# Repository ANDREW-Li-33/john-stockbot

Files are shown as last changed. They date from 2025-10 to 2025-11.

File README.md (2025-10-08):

# John Stockbot
*A Mobile Autonomous Basketball Rebounding & Training Machine*

## About

John Stockbot is an autonomous robot designed to catch basketballs before they hit the ground and pass them back to players during practice sessions. Named after NBA legend John Stockton (the all-time assists leader), this robot aims to be the ultimate robotic training partner for basketball players.

The robot uses computer vision to track basketball trajectories in real-time, positions itself to intercept shots, and uses a dual-flywheel system to return passes to anywhere on the court. The system is built on a distributed architecture with a Jetson Orin Nano handling high-level intelligence and a Teensy 4.1 managing motor control.

## Design Documents

| Document | Description | Link |
|---|---|---|
| **Primary Objectives** | Project goals, success metrics, and development principles | [Google Doc](https://docs.google.com/document/d/1Vo0fm0xn1nyjWS2_vyuDy4Y2yRpmGPdnU__JquevN0A/edit?tab=t.0) |
| **System Architecture** | Technical design, ROS2 nodes, and communication protocols | [Google Doc](https://docs.google.com/document/d/1LGaEFNWjZb3376pkYbGlLpHBF5ra2i3nYetyKKqaXto/edit?usp=sharing) |
| **Development Timeline** | 8-week development roadmap and phases | [Google Doc](https://docs.google.com/document/d/1ajr8lFJE9e5p4RsDfiWhvAvUYR6jIlyunh-4V3jgzBY/edit?usp=sharing) |
| **Parts List** | Complete bill of materials with costs and vendors | [Google Doc](https://docs.google.com/document/d/1YOarMHOIX9Ntcbo915CyfLngcIprZ0BvidMgzt3DbME/edit?usp=sharing) |
| **Progress Log** | A log documenting progress and steps taken each day | [Google Doc](https://docs.google.com/document/d/12o3Nwnd-CbdC7QZ4ZfDTg3oS7z87Sn4MFR_PtwYzXlk/edit?tab=t.0) |

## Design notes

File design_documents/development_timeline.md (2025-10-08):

## Project Duration: 9 Weeks

### Phase 1: Foundation (Weeks 1-3)

**Goal**: Establish core infrastructure and validate critical subsystems

* Model and design staging mechanism, feeding mechanism, and mobile base
* Finalize complete parts list and order remaining components:
    * Battery system
    * Staging mechanism parts
    * Feeding mechanism parts
    * Drivetrain components (motors, controllers, wheel mounts)
* Complete mechanical assembly of static platform
* Set up development environment (ROS2, CUDA, simulation)
* Validate sensor pipeline (ZED Mini → Jetson)
* Initial motor control testing (Teensy → motors)

**Key Milestone**: Subsystems fully assembled

### Phase 2: Core Functionality (Weeks 4-5)

**Goal**: Achieve basic catch and return capability

* Implement trajectory prediction algorithms
* Develop staging mechanism control software
* Tune flywheel launching
* Program ball capture/containment system
* Design ROS2 nodes for mobility (architecture preparation)
* Start basic drivetrain firmware development on Teensy
* Integration of vision → control pipeline

**Key Milestone**: First successful catch and return of stationary-launched ball

### Phase 3: Mobility Integration (Weeks 6-7)

**Goal**: Add mobile platform capabilities

* Week 6 - Physical Assembly:
    * Mount omni wheels to base
    * Install drivetrain motors and controllers
    * Connect motor controllers to Teensy
    * Attach static platform to mobile base
* Week 7 - Software Implementation:
    * Implement X-drive kinematics
    * Test basic movement commands
    * Develop path planning to intercept points
    * Create court awareness and boundary detection
    * Test mobile interception strategies

**Key Milestone**: First successful mobile intercept

### Phase 4: System Refinement (Weeks 8-9)

**Goal**: Polish, optimize performance, and prepare for extended use

* Full system integration testing
* Performance optimization to reach target metrics
* Implement adaptive trajectory prediction
* Add player detection and tracking
* Refine launch accuracy and power control
* Safety validation and failure mode testing
* Documentation and code cleanup
* Demo video preparation

**Key Milestone**: 90% catch rate achieved, 1-hour autonomous operation demo

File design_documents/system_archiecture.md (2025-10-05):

# John Stockbot - System Architecture

## Rationale

The system employs a** **hierarchical, distributed architecture combining high-level intelligence on the Jetson Orin Nano with real-time control on the Teensy 4.1. This separation removes computationally intensive vision processing from the Teensy’s precise but computationally constrained motor control capabilities, ensuring deterministic response times for safety-critical operations. The ROS2 framework provides standardized interfaces and tools for debugging, while the distributed nature ensures that a failure in one subsystem doesn't flow to others, improving overall system reliability.

## System Overview

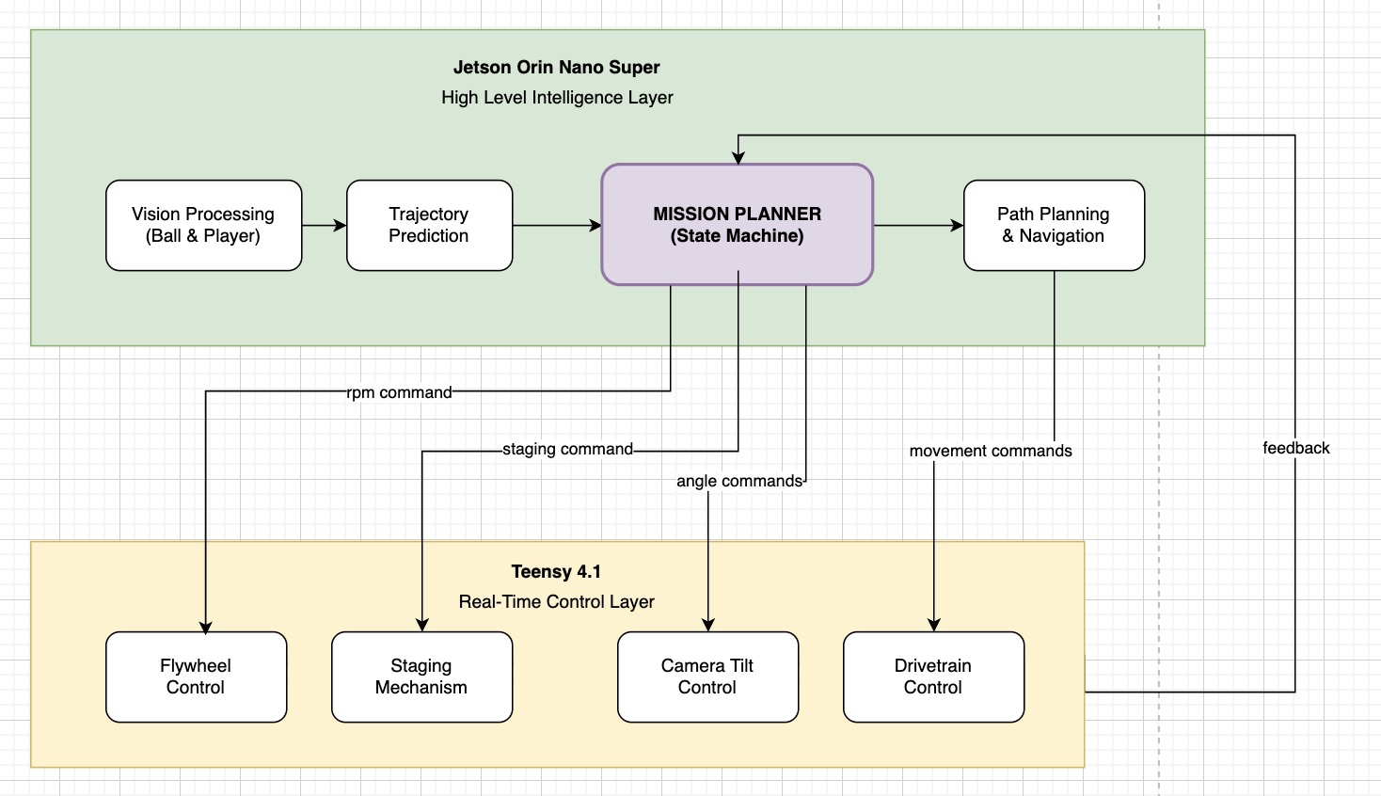
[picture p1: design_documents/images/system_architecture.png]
system_architecture image_tooltip


## Layer 1: Perception & Intelligence (Jetson Orin Nano)

### Vision Processing Node

**Responsibility**: Process ZED Mini camera data for object detection and tracking

* **Input**: RGB-D and depth stream
* **Processing**:
    * Ball detection using color segmentation + Hough circles
    * Player detection using pose estimation (OpenPose or MediaPipe)
    * Court boundary detection via line detection
* **Output**: Object positions in 3D world coordinates
* **Update Rate**: 30 Hz minimum

### Trajectory Prediction Node

**Responsibility**: Calculate ball flight path and intercept point

* **Input**: Ball position history (last 5-10 frames)
* **Processing**:
    * Kalman filter for state estimation
    * Physics model with drag coefficient
    * Confidence scoring for predictions
* **Output**: Predicted intercept point and time
* **Update Rate**: 30 Hz

### Mission Planning Node

**Responsibility**: High-level decision making and state management

* **States**:
    1. IDLE - Waiting for ball detection
    2. TRACKING - Following ball trajectory
    3. INTERCEPTING - Moving to catch position
    4. CATCHING - Executing catch sequence
    5. STAGING - Preparing ball for launch
    6. AIMING - Calculating launch parameters
    7. LAUNCHING - Executing pass
* **Output**: State commands and target positions
* **Update Rate**: 10 Hz

### Path Planning Node (Mobile Configuration)

**Responsibility**: Calculate optimal paths for interception

* **Input**: Current position, target intercept point, obstacles
* **Algorithm**: A* or RRT* for real-time planning
* **Output**: Waypoint sequence for drivetrain
* **Update Rate**: 10 Hz

## Layer 2: Real-Time Control (Teensy 4.1)

### Communication Interface

* **Protocol**: Custom binary protocol over Serial
* **Message Types**:
    * Motor commands (position, velocity, acceleration)
    * Sensor requests (encoder, IMU, limit switches)
    * Status updates (faults, temperatures, battery)
* **Bandwidth**: ~10 KB/s at 100 Hz update rate

### Flywheel Controller

**Responsibility**: Manage dual-motor flywheel system

* **Control Mode**: Closed-loop RPM control via ESCs
* **Sensors**: Hall effect for RPM feedback
* **Safety**: Soft-start, over-current protection
* **Performance**: 0-6000 RPM in &lt;2 seconds

### Staging Mechanism Controller

**Responsibility**: Control ball feeding into flywheel

* **Actuator**: NEMA 17 stepper with TMC2209 driver
* **Control**: Position control with AccelStepper library
* **Feedback**: Limit switches for home/end positions
* **Sequence**: Home → Load → Stage → Push → Retract

### Drivetrain Controller (Mobile Configuration)

**Responsibility**: Execute omnidirectional movement

* **Configuration**: 4-wheel X-drive with omni wheels
* **Control**: Inverse kinematics for wheel speeds
* **Feedback**: Encoder-based odometry
* **Performance**: 2 m/s max speed, 1 m/s² acceleration

### Camera Tilt Controller

**Responsibility**: Tilt camera for optimal tracking

* **Actuator**: NEMA 17 stepper motor
* **Control**: Position tracking of ball trajectory
* **Update Rate**: 50 Hz

## Scalability & Future Enhancements

### Modular Expansions

* LIDAR obstacle detection for navigation
* Speaker and microphone for user interaction

### Software Enhancements

* Shot prediction from player pose
* Handle and stage multiple balls simultaneously

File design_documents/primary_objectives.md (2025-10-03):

# John Stockbot - Primary Objectives
*Autonomous Basketball Rebounding & Training Assistant*

## Mission Statement
Develop an autonomous robot capable of intercepting basketballs in flight and returning them to players, initially as a static platform with future mobility capabilities.

## Core Objectives

### 1. Ball Detection & Tracking (Priority: Critical)
- **Objective**: Achieve robust real-time basketball detection and trajectory prediction
- **Success Metrics**:
  - Detection rate: >95% of shots from NBA 3-point line
  - Tracking latency: <50ms from detection to trajectory calculation
  - Trajectory prediction accuracy: ±20cm at intercept point
- **Key Requirements**:
  - Process ZED Mini depth + RGB data at minimum 30 FPS
  - Handle varying lighting conditions on indoor court
  - Track ball spin and account for Magnus effect in trajectory

### 2. Ball Interception (Priority: Critical)
- **Objective**: Successfully catch basketballs before ground contact
- **Success Metrics**:
  - Catching success rate: >90% for predicted intercepts within range
  - No damage to ball or safety hazards
  - Reliable ball containment post-catch
- **Key Requirements**:
  - Position accuracy: ±15cm at intercept point
  - Timing precision: ±100ms for intercept
  - Safe deceleration of ball momentum

### 3. Ball Return System (Priority: High)
- **Objective**: Return caught balls to player efficiently
- **Success Metrics**:
  - Launch consistency: ±1m accuracy at 10m distance
  - Return time: <3 seconds from catch to launch
  - Adjustable pass strength for various distances
- **Key Requirements**:
  - Flywheel speed control for variable pass distance (3-15m)
  - Reliable ball staging and feeding mechanism
  - Safety shutoff if player is too close

### 4. Platform Mobility (Priority: Medium - Phase 2)
- **Objective**: Enable autonomous navigation to optimal intercept positions
- **Success Metrics**:
  - Movement speed: >2 m/s
  - Positioning accuracy: ±10cm
  - Zero-turn capability for quick orientation changes
- **Key Requirements**:
  - Smooth omnidirectional movement via X-drive
  - Dynamic path planning to intercept point
  - Collision avoidance with court boundaries/obstacles

### 5. System Integration (Priority: High)
- **Objective**: Seamless coordination between all subsystems
- **Success Metrics**:
  - End-to-end latency: <200ms from detection to motion command
  - System reliability: >95% uptime during operation
  - Graceful failure handling
- **Key Requirements**:
  - Real-time communication between Jetson and Teensy
  - Synchronized control loops at 100Hz minimum
  - Robust error recovery mechanisms

## Development Principles

### Safety First
- Emergency stop capability at all times
- Soft-start for all motors
- Protected pinch points and moving parts
- Clear operational boundaries

### Iterative Development
- Start with static operation, validate core functionality
- Add mobility only after catching/passing proven
- Continuous testing on real court with real shots

### Modular Architecture
- Independent testing of each subsystem
- Clear interfaces between modules
- Version control for both hardware and software iterations

## Success Criteria for MVP (Month 1)
1. ✓ Detect and track basketball from 3-point line
2. ✓ Predict trajectory with <30cm error
3. ✓ Successfully catch 75% of straight shots
4. ✓ Return ball to fixed position via flywheel
5. ✓ Operate safely for 30-minute sessions

## Success Criteria for Version 1.0 (Month 2)
1. ✓ All MVP criteria at improved metrics
2. ✓ Mobile platform operational
3. ✓ Dynamic positioning for intercepts
4. ✓ Catch rate >90% within operational envelope
5. ✓ Variable distance passing with player tracking
6. ✓ 1-hour continuous operation capability

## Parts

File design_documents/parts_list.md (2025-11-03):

# Purchased Parts List

## Vision

<table>
  <tr>
   <td><strong>Quantity x Part</strong>
   </td>
   <td><strong>Category</strong>
   </td>
   <td><strong>Cost</strong>
   </td>
   <td><strong>Notes</strong>
   </td>
   <td><strong>Ord/Recv?</strong>
   </td>
   <td><strong>Vendor</strong>
   </td>
  </tr>
  <tr>
   <td>1x NEMA 17 Motor
   </td>
   <td>Motion
   </td>
   <td>$0
   </td>
   <td>Should have at home
   </td>
   <td>✅
   </td>
   <td>N/A
   </td>
  </tr>
  <tr>
   <td>1x Zed Mini camera
   </td>
   <td>Electronics
   </td>
   <td><a href="https://www.stereolabs.com/store/products/zed-mini">$400</a>
   </td>
   <td>
   </td>
   <td>✅ / ✅
   </td>
   <td>StereoLabs
   </td>
  </tr>
  <tr>
   <td>1x Flanged ball bearing (Flange 22mm OD, 6mm shaft hole)
   </td>
   <td>Motion
   </td>
   <td><a href="https://www.mcmaster.com/catalog/131/1424/57155K483">$9.97</a>
   </td>
   <td>
   </td>
   <td>✅ / ✅
   </td>
   <td>McMaster Carr
   </td>
  </tr>
  <tr>
   <td>2x M2 x 0.4 mm Thread, 6 mm Long
   </td>
   <td>Fasteners
   </td>
   <td><a href="https://www.mcmaster.com/catalog/131/3556/91290A013">$15.68</a>
   </td>
   <td>Fasten camera to attachment
   </td>
   <td>✅ / ✅
   </td>
   <td>McMaster Carr
   </td>
  </tr>
  <tr>
   <td>4x M3 x 0.5 mm Thread, 12 mm Long
   </td>
   <td>Fasteners
   </td>
   <td><a href="https://www.mcmaster.com/catalog/131/3556/91290A117">$11.29</a>
   </td>
   <td>Fasten tilt motor to base
   </td>
   <td>✅ / ✅
   </td>
   <td>McMaster Carr
   </td>
  </tr>
  <tr>
   <td>1x Right angle USB C extension
   </td>
   <td>Electronics
   </td>
   <td><a href="https://www.amazon.com/dp/B077XL7Q7H?ref_=ppx_hzsearch_conn_dt_b_fed_asin_title_1">$4.99</a>
   </td>
   <td>
   </td>
   <td>✅ / ✅
   </td>
   <td>Amazon
   </td>
  </tr>
  <tr>
   <td>2x TMC2209 V1.3 UART Stepper Motor Driver
   </td>
   <td>Electronics
   </td>
   <td><a href="https://www.amazon.com/dp/B08SMDY3SQ?ref=ppx_yo2ov_dt_b_fed_asin_title&th=1">$13.99</a>
   </td>
   <td>
   </td>
   <td>✅ / ✅
   </td>
   <td>Amazon
   </td>
  </tr>
  <tr>
   <td><strong>Total cost</strong>
   </td>
   <td><strong>All</strong>
   </td>
   <td><strong>$455.92</strong>
   </td>
   <td>
   </td>
   <td>
   </td>
   <td>
   </td>
  </tr>
</table>

## Flywheel

<table>
  <tr>
   <td><strong>Quantity x Part</strong>
   </td>
   <td><strong>Category</strong>
   </td>
   <td><strong>Cost</strong>
   </td>
   <td><strong>Notes</strong>
   </td>
   <td><strong>Ord/Recv?</strong>
   </td>
   <td><strong>Vendor</strong>
   </td>
  </tr>
  <tr>
   <td>2x electric speed controller
   </td>
   <td>Electronics
   </td>
   <td><a href="https://www.amazon.com/FLIPSKY-Electric-Controller-Skateboard-FSESC6-7/dp/B09MJZ8JRW">$152</a>
   </td>
   <td>For flywheel motors
   </td>
   <td>✅ / ✅
   </td>
   <td>Amazon
   </td>
  </tr>
  <tr>
   <td>2x motors (6384 120KV)
   </td>
   <td>Motion
   </td>
   <td><a href="https://www.aliexpress.us/item/3256808965567922.html">$202.84</a>
   </td>
   <td>To drive the flywheel
   </td>
   <td>✅ / ✅
   </td>
   <td>Aliexpress
   </td>
  </tr>
  <tr>
   <td>2x wheels (50mm x 200mm 70A)
   </td>
   <td>Motion
   </td>
   <td><a href="https://www.aliexpress.us/item/3256802735023252.html">$81.72</a>
   </td>
   <td>Belt grinder contact wheels for the flywheel
   </td>
   <td>✅ / ✅
   </td>
   <td>Aliexpress
   </td>
  </tr>
  <tr>
   <td>2x Timing Pulley (24T HTD, 20mm bore diameter, 16mm width)
   </td>
   <td>Motion
   </td>
   <td><a href="https://www.aliexpress.us/item/3256807191398660.html">$8.67</a>
   </td>
   <td>Timing pulley for jackshaft
   </td>
   <td>✅ / ✅
   </td>
   <td>Aliexpress
   </td>
  </tr>
  <tr>
   <td>2x Timing Pulley (24T HTD 5M, 10mm bore diameter, 16mm width)
   </td>
   <td>Motion
   </td>
   <td><a href="https://www.aliexpress.us/item/3256807191398660.html">$9.12</a>
   </td>
   <td>Timing pulley for motor shaft
   </td>
   <td>✅ / ✅
   </td>
   <td>Aliexpress
   </td>
  </tr>
  <tr>
   <td>2x Timing Belt (HTD 5M 15mm width, 300mm length)
   </td>
   <td>Motion
   </td>
   <td><a href="https://www.aliexpress.us/item/3256808065188881.html">$13.24</a>
   </td>
   <td>Timing belt
   </td>
   <td>✅ / ✅
   </td>
   <td>Aliexpress
   </td>
  </tr>
  <tr>
   <td>4x Bearing mount (KFL004 20mm shaft dia.)
   </td>
   <td>Structural
   </td>
   <td><a href="https://www.amazon.com/dp/B0F3D8BG1X">$25.98</a>
   </td>
   <td>Flush mounted bearings
   </td>
   <td>✅ / ✅
   </td>
   <td>Amazon
   </td>
  </tr>
  <tr>
   <td>2x Rotary shaft (25mm dia. 400mm lg.)
   </td>
   <td>Motion
   </td>
   <td><a href="https://www.mcmaster.com/catalog/131/1369/1482K43">$47.34</a>
   </td>
   <td>Jackshaft - To be keyed later using manual mill
   </td>
   <td>✅ / ✅
   </td>
   <td>McMaster Carr
   </td>
  </tr>
  <tr>
   <td>4x 10pcs M5, 25mm screws
   </td>
   <td>Structural
   </td>
   <td><a href="https://www.aliexpress.us/item/3256805692722422.html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">$8.68</a>
   </td>
   <td>
   </td>
   <td>✅ / ✅
   </td>
   <td>Aliexpress
   </td>
  </tr>
  <tr>
   <td>1x 10pcs M6, 40mm screws
   </td>
   <td>Structural
   </td>
   <td><a href="https://www.aliexpress.us/item/3256805692722422.html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">$3.22</a>
   </td>
   <td>
   </td>
   <td>✅ / ✅
   </td>
   <td>Aliexpress
   </td>
  </tr>
  <tr>
   <td>4x 10pcs M6, 35mm screws
   </td>
   <td>Structural
   </td>
   <td><a href="https://www.aliexpress.us/item/3256805692722422.html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">$12.08</a>
   </td>
   <td>
   </td>
   <td>✅ / ✅
   </td>
   <td>Aliexpress
   </td>
  </tr>
  <tr>
   <td>1x 10pcs M4, 16mm screws
   </td>
   <td>Structural
   </td>
   <td><a href="https://www.aliexpress.us/item/3256805692722422.html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">$1.48</a>
   </td>
   <td>
   </td>
   <td>✅ / ✅
   </td>
   <td>Aliexpress
   </td>
  </tr>
  <tr>
   <td>2x 10pcs M4, 80mm screws
   </td>
   <td>Structural
   </td>
   <td><a href="https://www.aliexpress.us/item/3256805692722422.html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">$6.04</a>
   </td>
   <td>
   </td>
   <td>✅ / ✅
   </td>
   <td>Aliexpress
   </td>
  </tr>
  <tr>
   <td>1x black carbon steel, 100pcs M6 locknuts
   </td>
   <td>Structural
   </td>
   <td><a href="https://www.aliexpress.us/item/2251832612458814.html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">$7.09</a>
   </td>
   <td>
   </td>
   <td>✅ / ✅
   </td>
   <td>Aliexpress
   </td>
  </tr>
  <tr>
   <td>1x black carbon steel, 25pcs M4 locknuts
   </td>
   <td>Structural
   </td>
   <td><a href="https://www.aliexpress.us/item/2251832612458814.html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">$1.96</a>
   </td>
   <td>
   </td>
   <td>✅ / ✅
   </td>
   <td>Aliexpress
   </td>
  </tr>
  <tr>
   <td>1x M5 5PCS, (L)75mm female standoff
   </td>
   <td>Structural
   </td>
   <td><a href="https://www.aliexpress.us/item/3256807000745548.html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">$20.4</a>
   </td>
   <td>
   </td>
   <td>✅ / ✅
   </td>
   <td>Aliexpress
   </td>
  </tr>
  <tr>
   <td>4x 25mm shaft dia. shaft collar
   </td>
   <td>Fasteners
   </td>
   <td><a href="https://www.aliexpress.us/item/3256808031076745.html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">$9.2</a>
   </td>
   <td>
   </td>
   <td>✅ / ✅
   </td>
   <td>Aliexpress
   </td>
  </tr>
  <tr>
   <td>4x 20mm shaft dia. shaft collar
   </td>
   <td>Fasteners
   </td>
   <td><a href="https://www.aliexpress.us/item/3256808031076745.html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">$7.6</a>
   </td>
   <td>
   </td>
   <td>✅ / ✅
   </td>
   <td>Aliexpress
   </td>
  </tr>
  <tr>
   <td>2x 20mm keyed shaft, 300mm length
   </td>
   <td>Motion
   </td>
   <td><a href="https://www.mcmaster.com/catalog/131/1371/1439K611">$76.94</a>
   </td>
   <td>For flywheel jackshaft
   </td>
   <td>✅ / ✅
   </td>
   <td>McMaster Carr
   </td>
  </tr>
  <tr>
   <td><strong>Total cost</strong>
   </td>
   <td><strong>All</strong>
   </td>
   <td><strong>$695.6</strong>
   </td>
   <td>
   </td>
   <td>
   </td>
   <td>
   </td>
  </tr>
</table>

## Staging

<table>
  <tr>
   <td><strong>Quantity x Part</strong>
   </td>
   <td><strong>Category</strong>
   </td>
   <td><strong>Cost</strong>
   </td>
   <td><strong>Notes</strong>
   </td>
   <td><strong>Ord/Recv?</strong>
   </td>
   <td><strong>Vendor</strong>
   </td>
  </tr>
  <tr>
   <td>2x IR Break Beam Sensor
   </td>
   <td>Electronics
   </td>
   <td><a href="https://www.adafruit.com/product/2168?srsltid=AfmBOoobAjaUanAoR-IGaYqmC2RcY8Lh0k4uOqCRmNNsachYmS5xqmzi">$11.9</a>
   </td>
   <td>
   </td>
   <td>✅ / ✅
   </td>
   <td>Adafruit
   </td>
  </tr>
</table>

## Drivetrain

<table>
  <tr>
   <td><strong>Quantity x Part</strong>
   </td>
   <td><strong>Category</strong>
   </td>
   <td><strong>Cost</strong>
   </td>
   <td><strong>Notes</strong>
   </td>
   <td><strong>Ord/Recv?</strong>
   </td>
   <td><strong>Vendor</strong>
   </td>
  </tr>
  <tr>
   <td>4x 6" omni wheels
   </td>
   <td>Motion
   </td>
   <td><a href="https://www.vexrobotics.com/omni-wheels.html">$60</a>
   </td>
   <td>v1 wheels
   </td>
   <td>✅ / ✅
   </td>
   <td>VEX
   </td>
  </tr>
  <tr>
   <td>2x FLIPSKY Dual Mini FSESC6.7 Pro 140A base on VESC6.6 
   </td>
   <td>Electronics
   </td>
   <td><a href="https://flipsky.net/products/dual-mini-fsesc6-7-pro-140a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">$252</a>
   </td>
   <td>
   </td>
   <td>✅ / ❌
   </td>
   <td>FLIPSKY
   </td>
  </tr>
  <tr>
   <td>4x 6354 BLDC motor 170KV 10MM D Shaft
   </td>
   <td>Motion
   </td>
   <td><a href="https://flipsky.net/products/6354-motor?variant=46506149019889">$255</a>
   </td>
   <td>
   </td>
   <td>✅ / ❌
   </td>
   <td>FLIPSKY
   </td>
  </tr>
  <tr>
   <td>FLIPSKY shipping
   </td>
   <td>MISC
   </td>
   <td>$99
   </td>
   <td>expensive shipping
   </td>
   <td>
   </td>
   <td>FLIPSKY
   </td>
  </tr>
  <tr>
   <td>½” ID flanged bearings
   </td>
   <td>Motion
   </td>
   <td><a href="https://www.amazon.com/gp/product/B07H4MJF23/ref=ox_sc_act_image_1?smid=A3BDHA3CPU6FI5&psc=1">$34</a>
   </td>
   <td>
   </td>
   <td>✅ / ✅
   </td>
   <td>Amazon
   </td>
  </tr>
  <tr>
   <td>20x M4 screws, 50mm length
   </td>
   <td>Fasteners
   </td>
   <td><a href="https://www.aliexpress.us/item/3256808898544302.html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">$7.94</a>
   </td>
   <td>24x required for complete wheel hub, ordered 20, but can 
   </td>
   <td>✅ / ❌
   </td>
   <td>Aliexpress
   </td>
  </tr>
  <tr>
   <td>25x M4 nuts
   </td>
   <td>Fasteners
   </td>
   <td><a href="https://www.aliexpress.us/item/2251832612458814.html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">$1.75</a>
   </td>
   <td>24x required for complete wheel hub
   </td>
   <td>✅ / ❌
   </td>
   <td>Aliexpress
   </td>
  </tr>
  <tr>
   <td>4x 425mm HTD 5M belt, 15mm width 
   </td>
   <td>Motion
   </td>
   <td><a href="https://www.aliexpress.us/item/3256806351155751.html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">$32.24</a>
   </td>
   <td>for motor to intermediate shaft
   </td>
   <td>✅ / ❌
   </td>
   <td>Aliexpress
   </td>
  </tr>
  <tr>
   <td>4x 595mm HTD 5M belt, 15mm width
   </td>
   <td>Motion
   </td>
   <td><a href="https://www.aliexpress.us/item/3256806351155751.html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">$32.24</a>
   </td>
   <td>for intermediate to wheel shaft
   </td>
   <td>✅ / ❌
   </td>
   <td>Aliexpress
   </td>
  </tr>
  <tr>
   <td>10x Aluminum extrusions, 1000mm x 20mm x 20mm
   </td>
   <td>Structural
   </td>
   <td><a href="https://www.aliexpress.us/item/3256809654557846.html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">$48.89</a>
   </td>
   <td>
   </td>
   <td>✅ / ❌
   </td>
   <td>Aliexpress
   </td>
  </tr>
  <tr>
   <td>20x M5 screws, 20mm length
   </td>
   <td>Fasteners
   </td>
   <td><a href="https://www.aliexpress.us/item/3256808898544302.html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">$8.08</a>
   </td>
   <td>For mounting the extrusions
   </td>
   <td>✅ / ❌
   </td>
   <td>Aliexpress
   </td>
  </tr>
  <tr>
   <td>50x M6 screws, 35mm length
   </td>
   <td>Fasteners
   </td>
   <td><a href="https://www.aliexpress.us/item/3256808898544302.html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">$38.7</a>
   </td>
   <td>48x required for 3d printed brackets
   </td>
   <td>✅ / ❌
   </td>
   <td>Aliexpress
   </td>
  </tr>
  <tr>
   <td>50x M6 nuts
   </td>
   <td>Fasteners
   </td>
   <td><a href="https://www.aliexpress.us/item/2251832612458814.html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">$4.62</a>
   </td>
   <td>48x required for 3d printed brackets
   </td>
   <td>✅ / ❌
   </td>
   <td>Aliexpress
   </td>
  </tr>
  <tr>
   <td>8x Keyed Shaft, 1/2" diameter, 6" length
   </td>
   <td>Motion
   </td>
   <td><a href="https://www.mcmaster.com/catalog/131/1370/1497K8">$111.52</a>
   </td>
   <td>
   </td>
   <td>✅ / ✅
   </td>
   <td>McMaster Carr
   </td>
  </tr>
  <tr>
   <td><strong>Total cost</strong>
   </td>
   <td><strong>All</strong>
   </td>
   <td><strong>$985.98</strong>
   </td>
   <td>
   </td>
   <td>
   </td>
   <td>
   </td>
  </tr>
</table>

## Electronics

<table>
  <tr>
   <td><strong>Quantity x Part</strong>
   </td>
   <td><strong>Category</strong>
   </td>
   <td><strong>Cost</strong>
   </td>
   <td><strong>Notes</strong>
   </td>
   <td><strong>Ord/Recv?</strong>
   </td>
   <td><strong>Vendor</strong>
   </td>
  </tr>
  <tr>
   <td>1x Jetson Orin Nano Super Developer Kit
   </td>
   <td>Electronics
   </td>
   <td><a href="https://www.amazon.com/NVIDIA-Jetson-Orin-Nano-Developer/dp/B0BZJTQ5YP">$249</a>
   </td>
   <td>Orin Nano, not just Nano
   </td>
   <td>✅ / ✅
   </td>
   <td>Amazon
   </td>
  </tr>
  <tr>
   <td>1x Teensy 4.1
   </td>
   <td>Electronics
   </td>
   <td><a href="https://www.amazon.com/dp/B088JY7P2H">$35.00</a>
   </td>
   <td>
   </td>
   <td>✅ / ✅
   </td>
   <td>Amazon
   </td>
  </tr>
  <tr>
   <td>1x 24V power supply
   </td>
   <td>Electronics
   </td>
   <td><a href="https://www.amazon.com/dp/B078RY7BPL">$15.99</a>
   </td>
   <td>Plugs into outlet
   </td>
   <td>✅ / ✅
   </td>
   <td>Amazon
   </td>
  </tr>
  <tr>
   <td><strong>Total cost</strong>
   </td>
   <td><strong>All</strong>
   </td>
   <td><strong>$299.99</strong>
   </td>
   <td>
   </td>
   <td>
   </td>
   <td>
   </td>
  </tr>
</table>

## Misc

<table>
  <tr>
   <td><strong>Quantity x Part</strong>
   </td>
   <td><strong>Category</strong>
   </td>
   <td><strong>Cost</strong>
   </td>
   <td><strong>Notes</strong>
   </td>
   <td><strong>Ord/Recv?</strong>
   </td>
   <td><strong>Vendor</strong>
   </td>
  </tr>
  <tr>
   <td>1x Wilson Basketball
   </td>
   <td>Misc
   </td>
   <td><a href="https://www.amazon.com/dp/B091MQ4P7D">$26.99</a>
   </td>
   <td>
   </td>
   <td>✅ / ✅
   </td>
   <td>Amazon
   </td>
  </tr>
  <tr>
   <td>1x Air pump
   </td>
   <td>Misc
   </td>
   <td><a href="https://www.amazon.com/dp/B01A425KQW">$11.99</a>
   </td>
   <td>
   </td>
   <td>✅ / ✅
   </td>
   <td>Amazon
   </td>
  </tr>
  <tr>
   <td>1x DisplayPort to HDMI cable, unidirectional
   </td>
   <td>Misc
   </td>
   <td><a href="https://www.amazon.com">$8.54</a>
   </td>
   <td>For the Jetson Orin Nano
   </td>
   <td>✅ / ✅
   </td>
   <td>Amazon
   </td>
  </tr>
  <tr>
   <td>1x Fusion 360 Advanced HTD Timing Pulley Generator plugin
   </td>
   <td>Misc
   </td>
   <td><a href="https://apps.autodesk.com/FUSION/en/Detail/Index?id=5614470164717391487&appLang=en&os=Win64&isFromPaypal=true">$20.00</a>
   </td>
   <td>Speed up CAD development time for drivetrain and save costs (for example, a 72T HTD 5M pulley would have costed me over $50 each, but now I can just 3d print it using this plugin)
   </td>
   <td>N/A
   </td>
   <td>Fusion 360 / LayerFusion
   </td>
  </tr>
  <tr>
   <td><strong>Total cost</strong>
   </td>
   <td><strong>All</strong>
   </td>
   <td><strong>$67.52</strong>
   </td>
   <td>
   </td>
   <td>
   </td>
   <td>
   </td>
  </tr>
</table>

---

**Project Total: $2,516.91**

# **Printed parts**

<table>
  <tr>
   <td>Part name
   </td>
   <td>Component
   </td>
   <td>Qty
   </td>
   <td>Started?
   </td>
   <td>Received?
   </td>
  </tr>
  <tr>
   <td>Camera attachment
   </td>
   <td>Vision
   </td>
   <td>1
   </td>
   <td>✅
   </td>
   <td>✅
   </td>
  </tr>
  <tr>
   <td>Tilt motor base
   </td>
   <td>Vision
   </td>
   <td>1
   </td>
   <td>✅
   </td>
   <td>✅
   </td>
  </tr>
  <tr>
   <td>Motor side inner bracket
   </td>
   <td>Flywheel
   </td>
   <td>2
   </td>
   <td>✅
   </td>
   <td>❌
   </td>
  </tr>
  <tr>
   <td>No motor side bracket
   </td>
   <td>Flywheel
   </td>
   <td>2
   </td>
   <td>❌
   </td>
   <td>❌
   </td>
  </tr>
  <tr>
   <td>Printed nut cover
   </td>
   <td>Flywheel
   </td>
   <td>4
   </td>
   <td>❌
   </td>
   <td>❌
   </td>
  </tr>
  <tr>
   <td>wheel attachment
   </td>
   <td>Flywheel
   </td>
   <td>4
   </td>
   <td>❌
   </td>
   <td>❌
   </td>
  </tr>
  <tr>
   <td>ball bearing mount
   </td>
   <td>Drivetrain
   </td>
   <td>16
   </td>
   <td>❌
   </td>
   <td>❌
   </td>
  </tr>
  <tr>
   <td>wheel hub
   </td>
   <td>Drivetrain
   </td>
   <td>8
   </td>
   <td>❌
   </td>
   <td>❌
   </td>
  </tr>
  <tr>
   <td>plate connector motor side
   </td>
   <td>Drivetrain
   </td>
   <td>4
   </td>
   <td>❌
   </td>
   <td>❌
   </td>
  </tr>
  <tr>
   <td>plate connector
   </td>
   <td>Drivetrain
   </td>
   <td>4
   </td>
   <td>❌
   </td>
   <td>❌
   </td>
  </tr>
  <tr>
   <td>right angle actual
   </td>
   <td>Drivetrain
   </td>
   <td>4
   </td>
   <td>❌
   </td>
   <td>❌
   </td>
  </tr>
  <tr>
   <td>wheel 90T pulley
   </td>
   <td>Drivetrain
   </td>
   <td>4
   </td>
   <td>❌
   </td>
   <td>❌
   </td>
  </tr>
  <tr>
   <td>intermediate 20T pulley
   </td>
   <td>Drivetrain
   </td>
   <td>4
   </td>
   <td>❌
   </td>
   <td>❌
   </td>
  </tr>
  <tr>
   <td>intermediate 72T pulley
   </td>
   <td>Drivetrain
   </td>
   <td>4
   </td>
   <td>❌
   </td>
   <td>❌
   </td>
  </tr>
  <tr>
   <td>motor 24T pulley
   </td>
   <td>Drivetrain
   </td>
   <td>4
   </td>
   <td>❌
   </td>
   <td>❌
   </td>
  </tr>
</table>

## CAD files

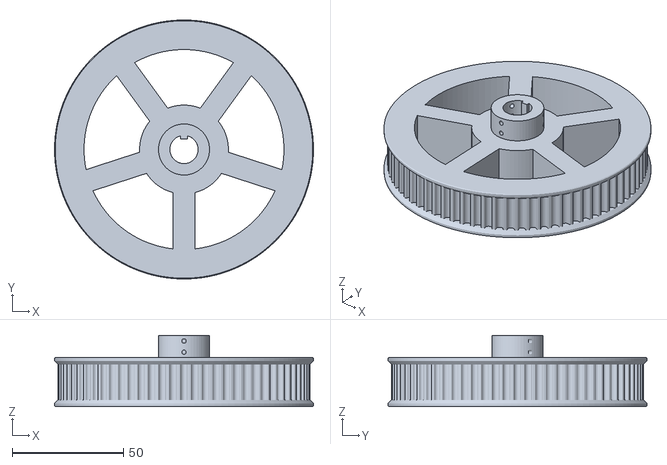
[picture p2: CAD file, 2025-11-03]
printed parts/drivetrain printed parts/intermediate_72T_pulley.stl
116.6 x 116.6 x 32.0

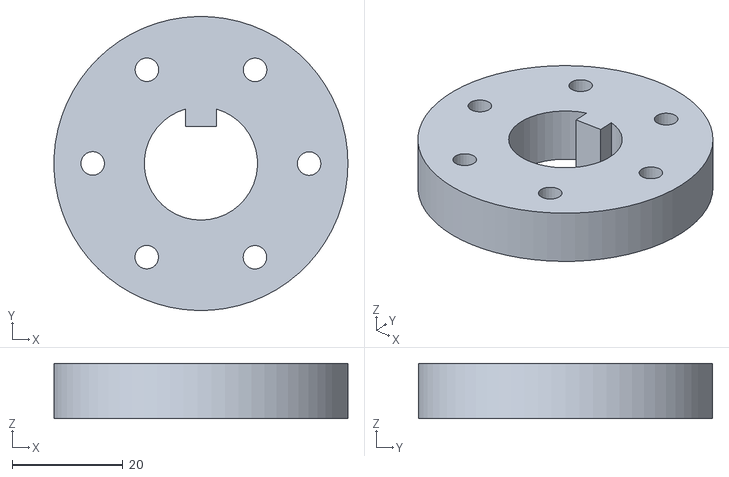
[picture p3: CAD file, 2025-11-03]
printed parts/flywheel printed parts/wheel attachment.stl
53.0 x 53.0 x 10.0

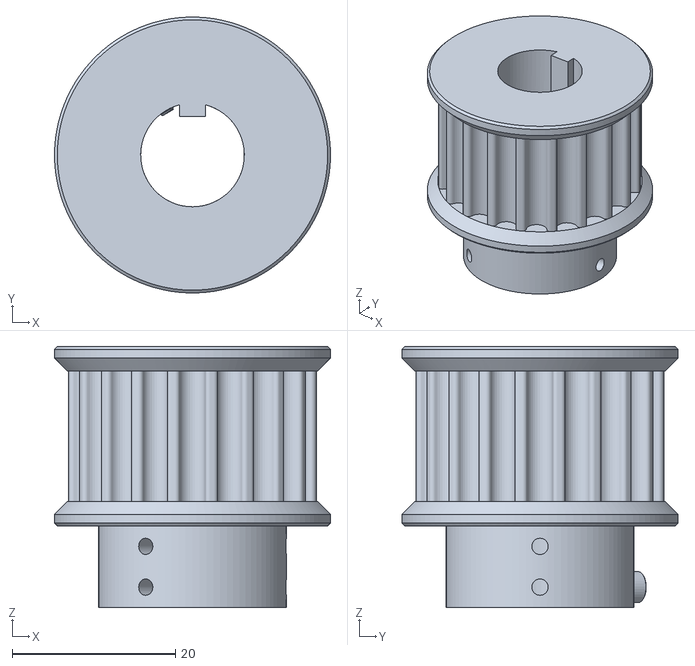
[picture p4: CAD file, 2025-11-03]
printed parts/drivetrain printed parts/intermediate_20T_pulley.stl
33.8 x 33.8 x 32.0

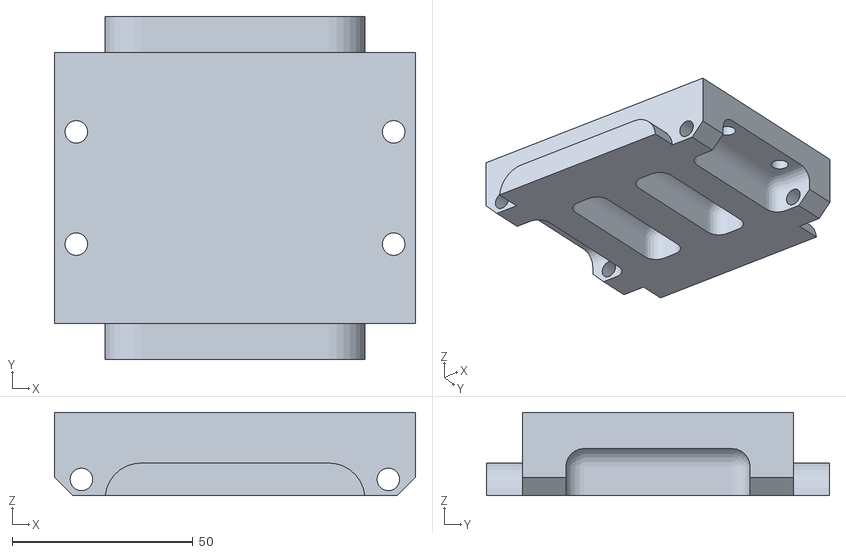
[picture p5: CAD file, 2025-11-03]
printed parts/flywheel printed parts/motor side inner bracket.stl
100.0 x 95.0 x 23.0

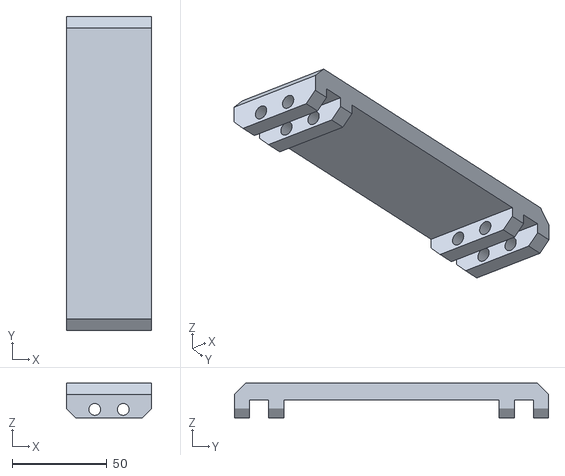
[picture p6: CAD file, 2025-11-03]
printed parts/drivetrain printed parts/plate connector.stl
45.0 x 165.7 x 18.4

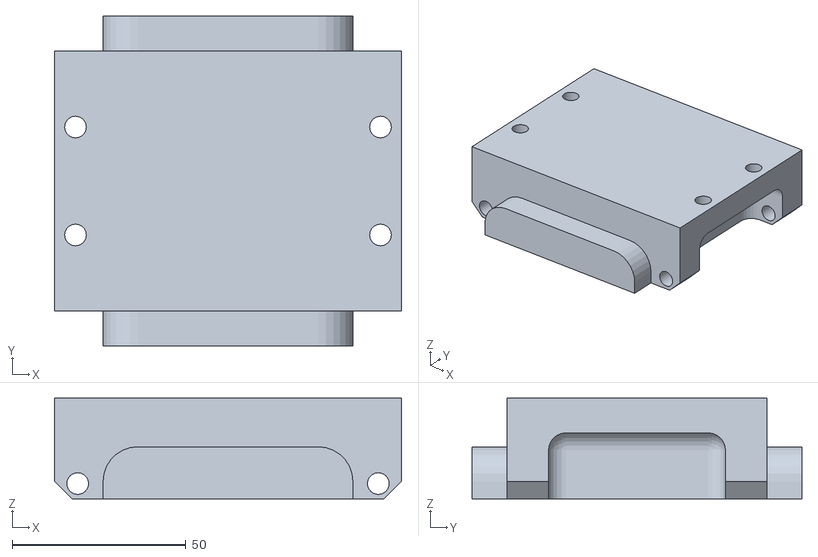
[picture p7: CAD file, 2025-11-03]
printed parts/flywheel printed parts/no motor side bracket.stl
100.0 x 95.0 x 29.0

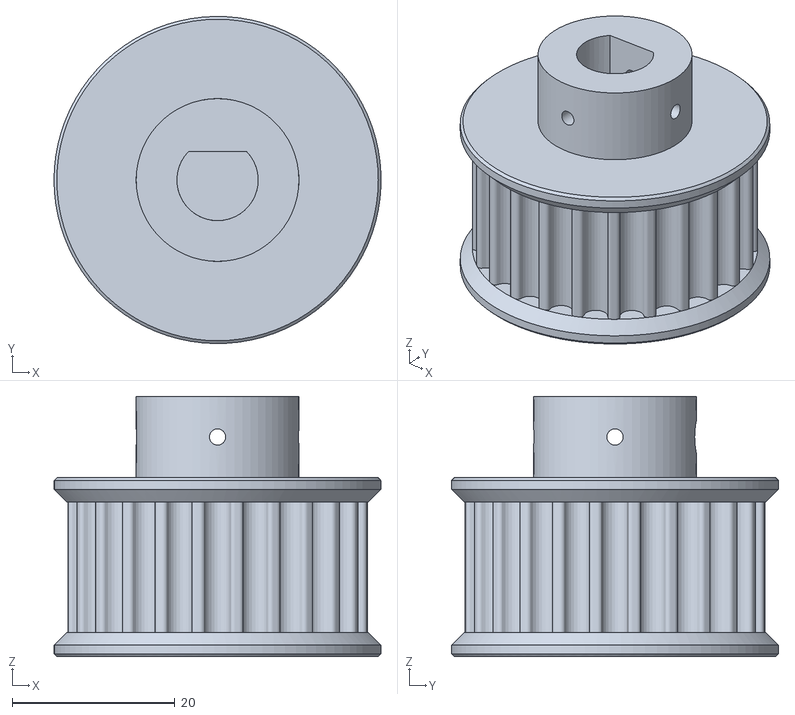
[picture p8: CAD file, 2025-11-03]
printed parts/drivetrain printed parts/motor_24T_pulley.stl
40.2 x 40.2 x 32.0

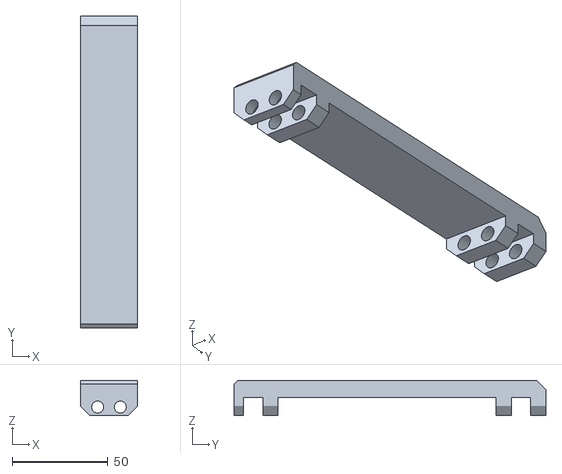
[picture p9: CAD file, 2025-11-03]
printed parts/drivetrain printed parts/plate connector motor side.stl
29.8 x 162.7 x 18.4

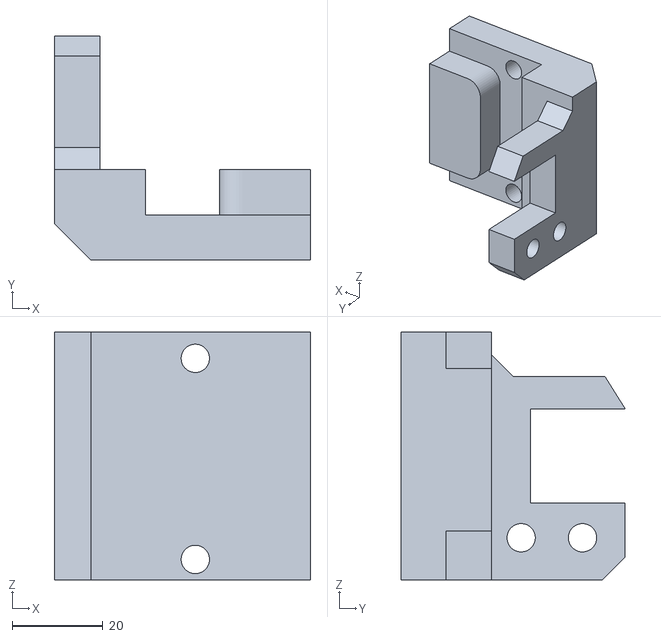
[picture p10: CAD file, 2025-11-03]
printed parts/drivetrain printed parts/right angle actual.stl
56.4 x 49.4 x 54.5

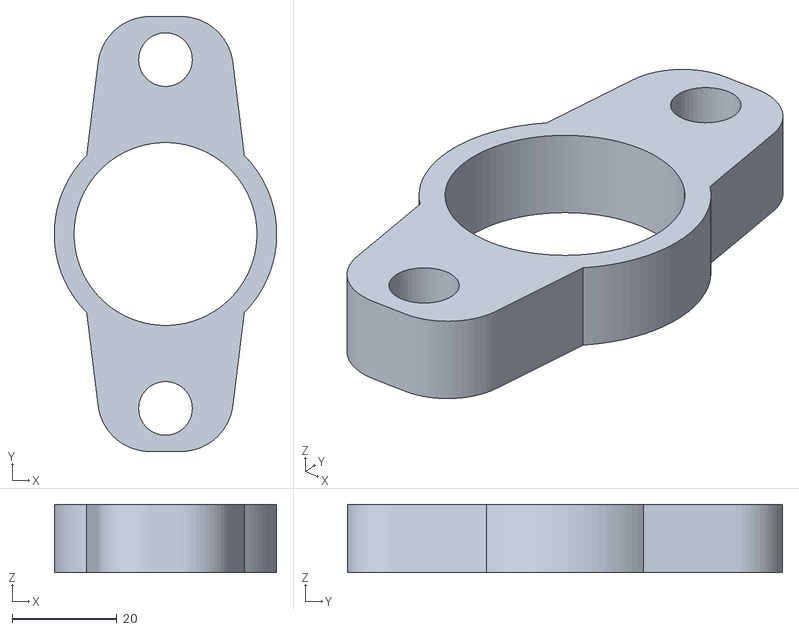
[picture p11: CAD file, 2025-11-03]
printed parts/drivetrain printed parts/ball bearing mount.stl
42.5 x 83.1 x 13.0

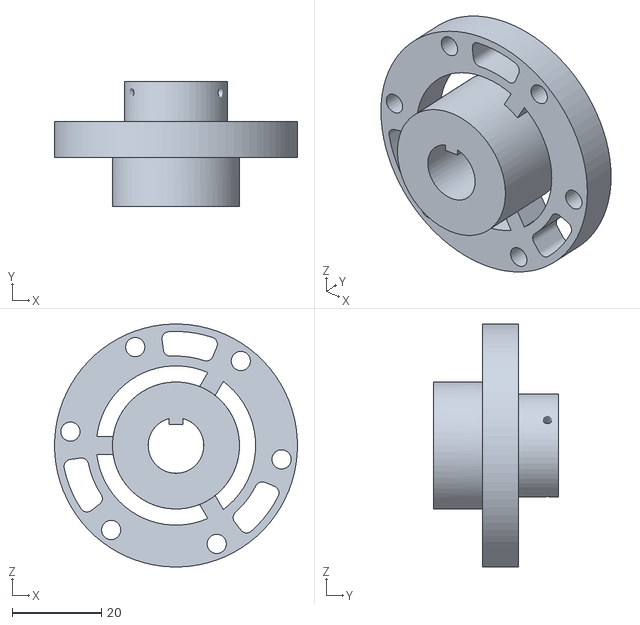
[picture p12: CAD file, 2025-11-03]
printed parts/drivetrain printed parts/wheel hub.stl
54.3 x 28.0 x 54.3

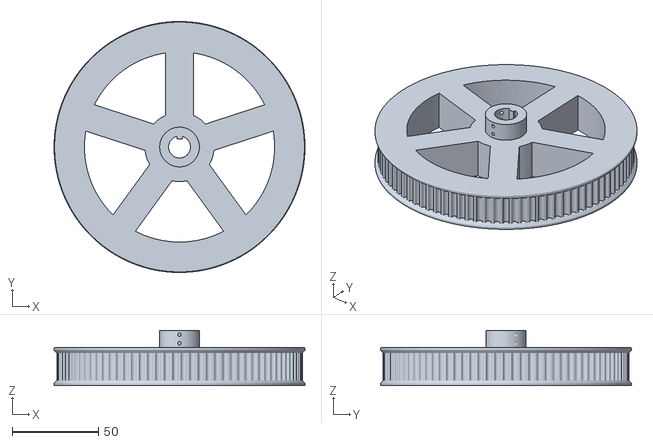
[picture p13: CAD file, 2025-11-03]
printed parts/drivetrain printed parts/wheel_90T_pulley.stl
145.2 x 145.2 x 32.0

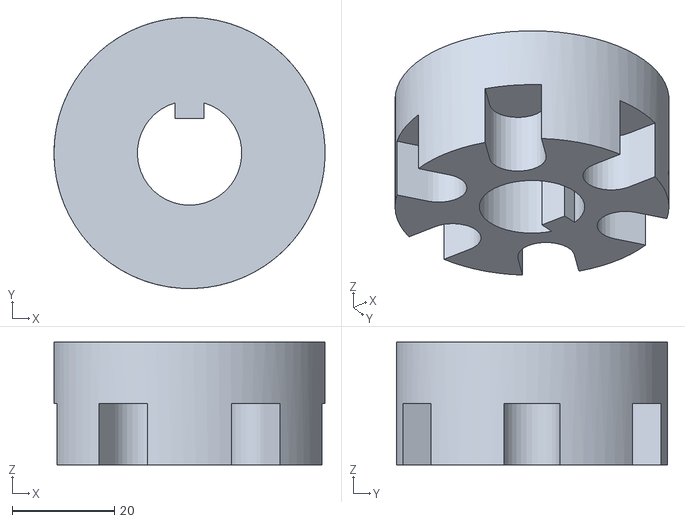
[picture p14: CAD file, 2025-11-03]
printed parts/flywheel printed parts/printed nut cover.stl
53.0 x 53.0 x 24.0

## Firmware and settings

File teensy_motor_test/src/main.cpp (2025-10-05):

#include <Arduino.h>

#define STEP_PIN 2
#define DIR_PIN 3
#define EN_PIN 6

void setup() {
  pinMode(STEP_PIN, OUTPUT);
  pinMode(DIR_PIN, OUTPUT);
  pinMode(EN_PIN, OUTPUT);

  Serial.begin(115200);
  Serial.println("Stepper one-direction test...");

  digitalWrite(EN_PIN, LOW);   // enable driver
  digitalWrite(DIR_PIN, LOW);  // fixed direction
}

void loop() {
  // send step pulses forever
  digitalWrite(STEP_PIN, HIGH);
  delayMicroseconds(800);
  digitalWrite(STEP_PIN, LOW);
  delayMicroseconds(800);
}

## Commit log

2025-10-05 camera tilt motor testing
2025-10-26 updated parts list for fusion pulley generator plugin
2025-10-28 updated parts list with drivetrain motors and electronics
2025-10-31 updated parts list with drivetrain costs
2025-11-03 updated parts list with printed parts
2025-11-03 uploaded printed parts
    [ball bearing mount.stl, intermediate_20T_pulley.stl, intermediate_72T_pulley.stl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]
2025-11-03 updated parts list with plate connectors
